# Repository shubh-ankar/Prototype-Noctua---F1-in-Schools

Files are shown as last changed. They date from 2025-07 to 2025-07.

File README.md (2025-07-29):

# 🦉 Prototype Noctua

Prototype Noctua is a miniature F1 model car we designed from scratch as Grade 12 students for STEM Racing (Previously F1 in Schools). The goal? Build something fast, aerodynamic, lightweight — and learn as much as possible while doing it.

Through design iterations, CFD analysis, and careful prototyping, we created a car that was not just regulation-compliant, but exceeded our expectations. This project helped us translate classroom theory into real engineering decisions.

---

## 🎯 Objectives

- Minimize aerodynamic drag (target: < 0.4 drag coefficient)
- Ensure directional stability via center of mass tuning
- Maximize downforce without violating regulations
- Use lightweight materials and precise manufacturing
- Apply core mechanical engineering principles (CFD, CAD, CAM)

---

## 🛠️ Tools Used

| Tool/Software | Purpose |
|---|---|
| Fusion 360 | 3D CAD modeling |
| SimScale | CFD simulations |
| CNC Milling | Chassis manufacturing |
| 3D Printing | Wings, wheels, tether guides |
| Vernier Calipers  | Precision post-manufacture checks|

---

## 📐 Methodology

### 1. **Research & Design**
- Studied F1 principles, boundary layer theory, Magnus effect
- Designed ~9 iterations of the car in Fusion 360
- Focused on smooth curvature to prevent flow separation

### 2. **Simulation & Analysis**
- Used **CFD** to study drag forces and wake patterns
- Ensured consistent test conditions with bounding boxes in simulations

### 3. **Manufacturing**
- CNC-milled chassis to precise tolerances
- SLA 3D-printed parts in resin for low mass and smooth surface
- Sanded and primed body, then painted using a tested spray process

---

## 📸 Sample Visuals

### 🔧 Final Car Render
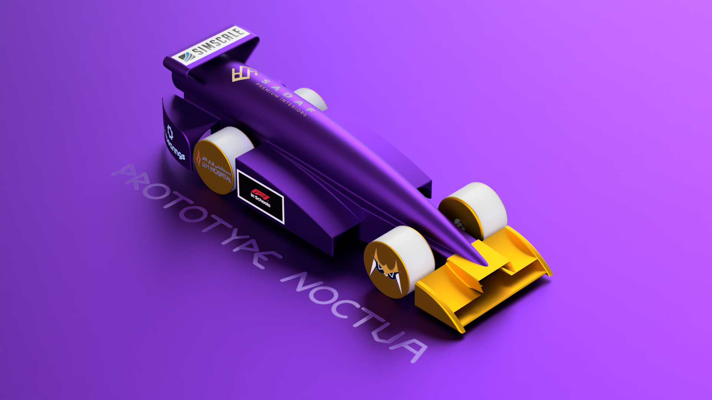
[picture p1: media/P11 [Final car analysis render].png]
Final Car

*A render of the final car body created in Fusion 360*

### 🌬️ Wake Analysis (CFD)
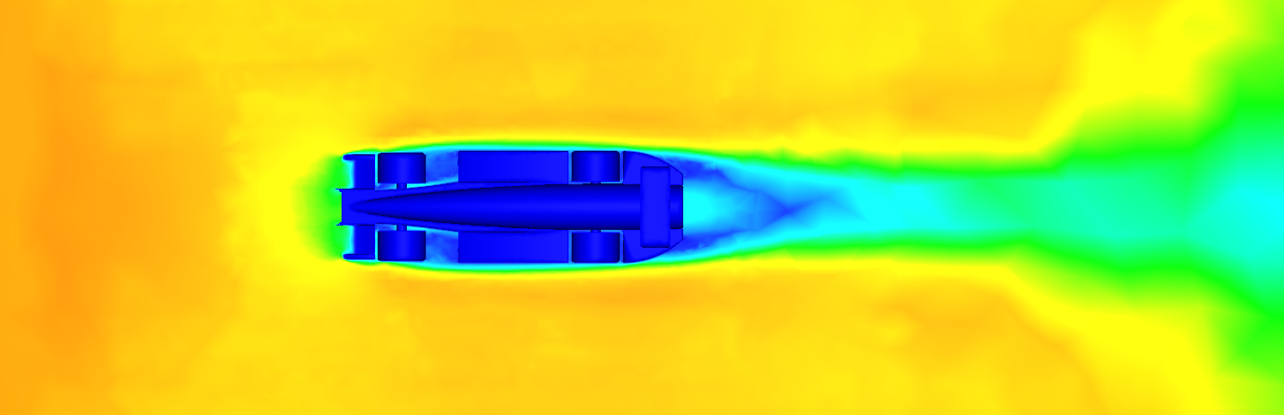
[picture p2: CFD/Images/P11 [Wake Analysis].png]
Wake CFD

*CFD wake analysis showing airflow and turbulence zones*

---

## 📊 Key Outcomes

- ✅ Final drag force: **0.28** (22% below target)
- ✅ Front wing downforce increased grip by ~15%
- ✅ Center of Mass optimized for both tip-resistance and directional control
- ✅ Weight balanced at ~50g (compliant with competition rules)
- ✅ Achieved aesthetically clean finish and structurally sound assembly

---

## 📚 What We Learned

- Iteration matters — small design tweaks made big simulation differences.
- CFD setups must be precise — boundary conditions can break results.
- Structural integrity must be balanced with aerodynamic needs.
- Manufacturing constraints (like drill bit sizes) affect CAD freedom.
- Documentation and teamwork were as important as the design.

---

## 📁 Folder Structure

```plaintext
Prototype-Noctua/
├── CAD/                        # STL files for all components
├── CFD/                       
│   └── Images/                 # CFD result images (e.g., Wake Analysis)
├── docs/                       # Project report, design plans, presentation
├── media/                      # Renders used in README
└── README.md                   # Project overview and instructions
```

---

## ✨ About the Name

**Noctua** is Latin for Owl, inspired by *Athene Noctua* — the Owl of Minerva, symbol of wisdom. Like the owl, we gained insight only after deep exploration and testing. Prototype Noctua is a reflection of that growth.

> *"Wisdom arrives only with dusk."* — G.W.F. Hegel

---

🚀 Thanks for checking out our project! Feedback is always welcome.

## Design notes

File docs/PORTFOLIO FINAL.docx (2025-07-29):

Final or sum

Car Objective:

After going through both the competition and critical regulations, we realized that the car gets us the most points. Hence, we had to keep a few clear objectives in mind so that we can acquire 100% of the allocated points. We divided the tasks in two:

1. Aerodynamics and Design:

Under this task, we had to achieve the following:

1. Drag Force of 0.4 or less | To ensure minimum point reduction from races
2. Aerodynamically efficiency | To ensure directional stability and reduce drag force
3. Innovative design that complies with regulations | Most of the allocated points can be lost in the criteria

2. Manufacturing:

Under this task, we had to achieve the following:

1. Weight | Maintain weight as close as 50g to achieve a lighter car
2. CNC milling and 3D printing | Overlook the design process to secure a millable design and decide what parts to print
3. Material selection | Select materials according to needs which are durable and easy to work with
4. Precision manufacturing | To acquire a model that closely replicates the CAD model
5. Paint | A paint that is lightweight and provides a smooth surface

These allowed us to visualize a final deliverable that would not only comply with the competition's regulations but also excel in innovation and performance maximizing the amount of points secured.

Initial Research

Through basic research of the forces a car experiences during its motion, we found that the forces experienced are: Thrust from the canister, Drag, Lift, Weight and downforce along with others.

Canister Thrust:

Canister thrust is a variable force that provides the prototype with the initial force to overcome its inertia. Hence, our goal was to maximize thrust efficiency by reducing inertia of the car and making it more streamlined. The nose cone design hugely impacts efficiency of the thrust and to achieve the highest provided thrust we need to design a nose cone that minimizes air resistance and is seamlessly integrated to the rest of the body.

Drag:

To reduce the drag, we had to ensure that the surface of the model was smooth and had smooth transitions throughout. Through applications of intricate designing techniques and aerodynamic principles, we had to make the model as streamlined as possible. To start with, we needed to create a front wing that would efficiently allow the airflow to be distributed over the rest of the body. Also, designing sidepods that flawlessly redirect airflow over and around the rear wheels such that it flows over the rear pods was essential.

Lift and downforce:

We had to minimize lift and maximize downforce so that our car is stable on the track and does not generate lift due to the initial thrust. To do so, we had to focus on the aerofoils of the front and rear wings, angle of attack of the nose cone and to implement ground effect.

Weight:

Heavier cars experience higher drag due to increased frontal area. Due to this, it’s harder to create downforce on heavier prototypes. Also, this hugely impacts inertia which can hence reduce the thrust efficiency. Hence, our aim was to create a model that would weigh as close to the 50g weight limit mandated by the regulations.

GENERAL RESEARCH

Boundary Layer Separation:

A boundary layer is a layer of fluid, which is slow-moving compared to the rest of the airflow, directly alongside a body immersed in that fluid. Boundary Layer Separation is the detachment of the boundary layer causing the formation of a wake. It occurs when the flow has reached an adverse pressure gradient where it has stopped and reversed its direction. To reduce boundary layer separation, we had to come up with a streamlined design with smooth surfaces. Filleting the edges was a major step taken in the design process as the sharp edges tended to create unwanted vortices and turbulent air flow.

Creating gradual curvature based body shapes proved to be beneficial as it maintains flow attachment and reduces adverse pressure gradients. We started to try and imply these with P7 in which we chamfered the ends of the body to replicate a gradual curve.

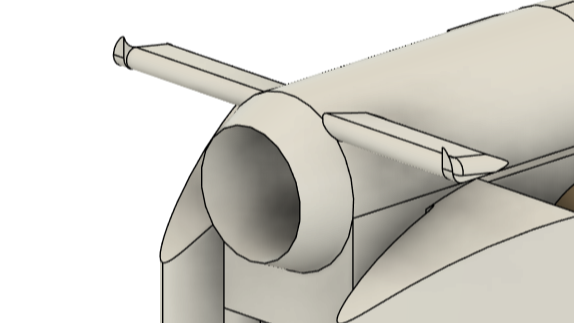
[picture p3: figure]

This evidently exhibited decrease in drag significantly but it hardly resembled a gradual curvature. We decided to look for ways to create a body that would replicate the tear drop shape and that came with the idea of the penguin shape.

Wake:

The wake is the region of turbulent airflow behind a car that is formed as it travels through air. This turbulent airflow creates a low pressure area inducing drag reducing overall efficiency.

When a body moves through air it creates a boundary layer. This layer is separated at the rear of the car creating a turbulent region with low pressure. Due to this low pressure area, a pressure difference is generated. The high pressure area at the front of the car pushes it while the low pressure area at the rear pulls it producing drag. This difference is not constant as the pressure at the rear keeps changing due to it being a turbulent area. This difference is directly proportional to pressure drag. Also, this turbulent region is more distinct with box-like rears.

Due to the wake, the car experiences a net force and can also face issues with handling.

To reduce the wake, we needed to create a streamlined design that would redirect airflow around the car.

[PIC]

Magnus Effect:

Experienced by the wheels in this case, Magnus effect is the phenomenon where, when the wheels come in contact with a fluid while moving in the opposite direction, they experience a force in a direction perpendicular to the direction of its motion. Here, wheels travel in the opposite direction of the airflow and a high pressure area is created on bottom. Due to the low relative velocity on top of the wheel, it experiences a low pressure area at the bottom of the wheel. Due to this, both a high and a low pressure area is realized, due to which a drag is experienced by the wheel. Basically, the relative speed of a wheel on top is faster than that of the vehicle and at the bottom is slower, creating rotational turbulence, inducing drag. To overcome this we needed to design a front wing that would reduce the contact of incoming airflow and the wheel.

[PIC]

Centre of Mass determination:

The center of mass of an object is the point at which the relative distribution of weight sums up to zero. For a symmetric object, the COM is in its geometric center whereas for an irregular object, the COM is at a point where the object can balance.

We considered the following to determine an approximate position for the COM:

Tipping force: (Rear COM)

The thrust provided by the CO2 canister becomes the tipping force for the car and the moment of force provided by the center of gravity of the car helps balance it out. So, our aim was to ensure that the torque provided by the tipping force should always be less than the torque by the center of mass.

T . h > W.d

T > (W . d)/h

where T is the force provided by the canister,

W is the weight of the car,

d is the perpendicular distance between W vector and the center of the front wheel,

h is the perpendicular distance between the T vector and the center of the front wheel.

Hence, we needed to ensure that the maximum force provided by the canister should be less than the right hand side (RHS).

From the equation, we see that we can maximize the RHS by either increasing the values of W or d, or by decreasing the value of h.

Since increasing the value of the weight of the car is unfavorable for other factors such as low inertia, and the value of h remains almost constant throughout the models, the only value we could afford to change was d. Hence, for a higher value of d, the center of mass was to be shifted to the back.

However, we can’t place the center of mass way towards the rear as it promotes oversteer, i.e. the car would turn more easily with a minimal force applied. Hence, we also considered directional stability of the car to balance this out. Another disadvantage of this was that it would enhance traction during the crucial moments of acceleration provided by the thrust because a high level of traction is very unfavorable as it slows down the rate of acceleration. Traction, simply put, is the frictional force which resists acceleration and helps the wheel to grip to the surface. Going by this, we can’t have extreme levels of traction so we aimed to achieve a traction in between high and low.

Directional stability: (Forward COM)

To induce understeer, we need to promote directional stability in the body which would make the chances of the car turning or changing paths less. To do so, we visualized and realized that a forward center of mass would help in maintaining the directional stability of the car along with producing lower traction in general.

To brief it up:

Forward COM | REAR COM
Promotes directional stability | Prevents the tipping moment
Promotes understeer | Promotes oversteer

From this table, we thus realized that balancing these factors is crucial and a COM right at the middle would be the most preferable for a favorable race time. Hence, after incorporating in the CO2 canisters in our model and setting the materials of 3D printed parts (i.e. front wing, rear wing, tether line guides,etc.), we achieved a center COM in the car:

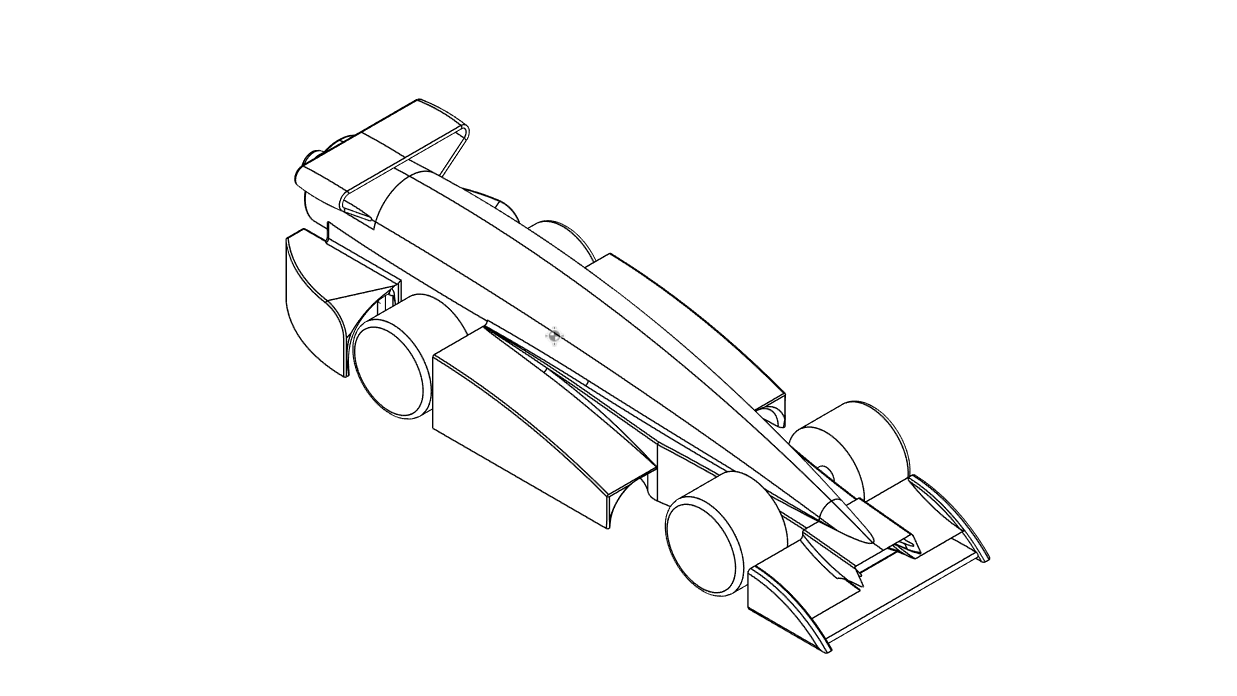
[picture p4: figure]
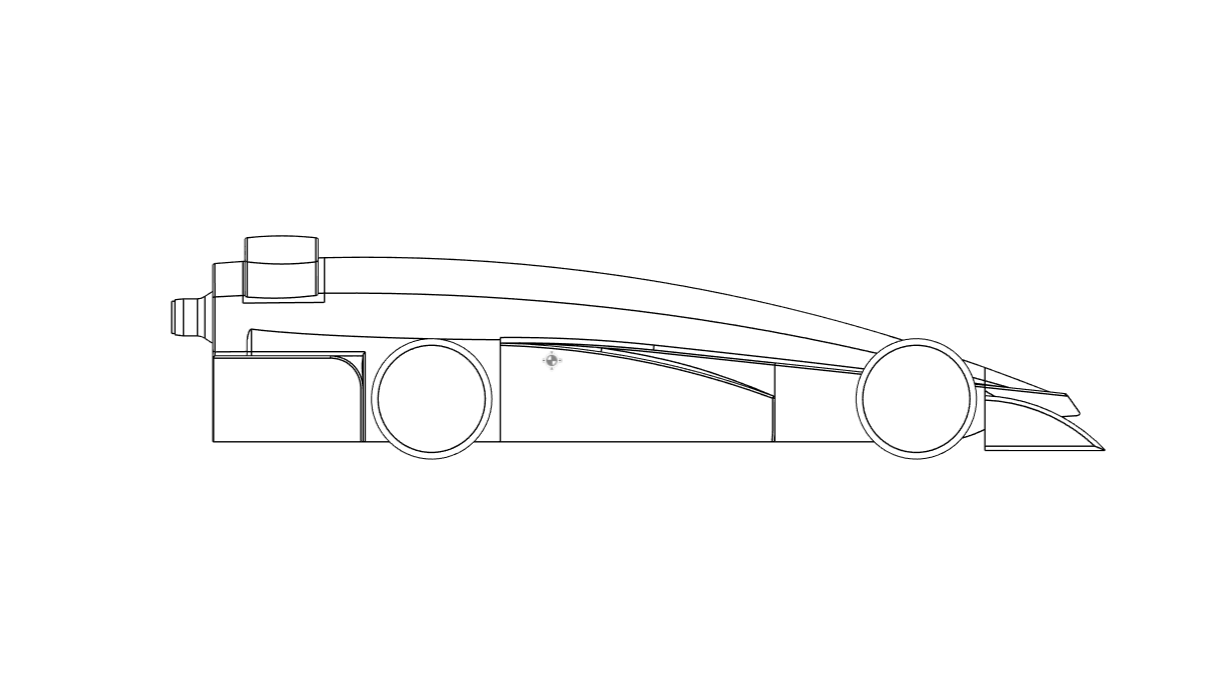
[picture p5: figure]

[USE SECOND ONE IMO]

The Centre of Mass tool displays a symbol at the observed Centre of Mass of the model. If all the materials are entered correctly, it displays the assumed Centre of Mass of the body. Indicated by

FOR CAD:

- What is CAD?

Computer Aided Design is the utilization of computers in support for designing, optimizing and analysis of any design.

The usage of CAD has proven to ease the storage, shareability and collaboration within engineers. There are 3 types of CAD softwares:

1. 2D CAD:

Aid the sketching and annotating process of a design. Mostly used for planning and layouting.

2. 3D CAD:

Aid the 3D modeling part of the designing process. 3D CAD provides an additional axis Z to facilitate 3D modeling.

It is made possible through wireframing and meshing. Wireframing is the skeletal representation of a real-world object whereas meshing is the process of dividing a complex object into smaller cells/elements.

3D CAD is of three types:

a. Parametric Modeling:

It allows users to define constraints and dimensions and edit them as soon as they have been defined. Using parametric modeling software, repetitive modifying is simplified but the existence of a history tree can stir up issues if major changes are made.

b. Explicit Modeling:

Unlike parametric modeling, explicit modeling does not rely on a history tree. The defined constraints and sketches directly become a part of the geometry created. Due to the absence of a history tree, repetitive modification is easier and expeditious. This flexibility gives the engineers the ability of rapid prototyping.

c. Assembly Modeling:

The incorporation of multiple pre-existing geometries into one.

3. Free Form CAD:

A technique that allows for the creation of more organic and graceful surfaces and solid shapes. It works on the concept of control points, splines and subdivisions. Free Forms can be combined with both parametric or explicit modeling to form complex geometries. Though it has its plus points, it is a complex technique which, if not executed well, can lead to complications like irregular transitions between two surfaces.

2D CAD | Aid the sketching and annotating process of a design. Mostly used for planning and layouting.

3D CAD

Aid the 3D modeling part of the designing process. 3D CAD provides an additional axis Z to facilitate 3D modeling.

It is made possible through wireframing and meshing. Wireframing is the skeletal representation of a real-world object whereas meshing is the process of dividing a complex object into smaller cells/elements.

3D CAD is of three types:

1. Parametric Modeling:

It allows users to define constraints and dimensions and edit them as soon as they have been defined. Using parametric modeling software, repetitive modifying is simplified but the existence of a history tree can stir up issues if major changes are made.

2. Explicit Modeling:

Unlike parametric modeling, explicit modeling does not rely on a history tree. The defined constraints and sketches directly become a part of the geometry created. Due to the absence of a history tree, repetitive modification is easier and expeditious. This flexibility gives the engineers the ability of rapid prototyping.

3. Assembly Modeling:

The incorporation of multiple pre-existing geometries into one.
Free Form CAD | A technique that allows for the creation of more organic and graceful surfaces and solid shapes. It works on the concept of control points, splines and subdivisions. Free Forms can be combined with both parametric or explicit modeling to form complex geometries. Though it has its plus points, it is a complex technique which, if not executed well, can lead to complications like irregular transitions between two surfaces.

[I ADDED THE TABLE JUST IN CASE U WANNA DO THAT SO YEE ITS THE SAME THING]

- Picking a software:

Fusion | Solid Works | Space Claim
Parametric/Explicit | Parametric | Explicit
Cloud Based | Not cloud based | Not cloud based
Simulation Tools | Simulation Tools | Ansys softwares have to be integrated
Manufacturing Integration | Manufacturing Integration | Ansys softwares have to be integrated
Free for students | Subscription | Free for students
Ease of usage | Ease of usage | Ease of usage

- Based on the above gathered information on the three of the reputed softwares, a decision had to be made to pick the ideal modeling application.
- Keeping affordability, cloud storage, user friendliness and access to training resources in mind, we chose to go with Fusion. Solid Works was immediately put aside due to its unaffordability and its high system requirements of 16 GB RAM and a quality GPU.

Space Claim was overlooked due to it being an explicit modeling software which would make it harder to edit dimensions and constraints if needed to. With the advantageous history tree, there would be no need to start geometries from scratch. Without constraints and parameters, it would’ve been hard to keep track of the design intent. Also, monitoring various parts of assemblies would be less efficient since design intent and interpart relationships are not maintained.

- Important features:
1. Sketches:

Sketches are the foundation of any geometry to be created as they define the design intent. In Fusion, shapes like circles, rectangles, ellipses, arcs, etc. are provided to ease sketching along with splines and constraints. Unconstrained sketches (indicated by: in Fusion) are useful for their flexibility and experimentality, but can affect the complex assemblies later on. Hence, it is important to create Constrained sketches (indicated by: in Fusion) once the design intent is clear to obtain a precise model.

2. Solids:

Solids are formed from sketches. Among the numerous functions Fusion provides, Extrude (indicated by: ), Loft (indicated by: ) and Sweep (indicated by: ) proved to be the most beneficial among all as evident later on.

Extrude tool adds depth to sketches. It can also be used to join (), cut () or intersect () two (or more) bodies. Loft tool creates smooth geometry between two sketch planes. Sweep tool creates a solid body along a path with a defined profile and can perform the same operations as Extrude and Loft.

3. Tools for modification of Solids:
a. Fillet:

Fillet tool () smoothens the edges of a solid body by rounding them or by adding material between two edges.

b. Chamfer:

Chamfer tool () bevels the edges of a solid body by eliminating material at the edges.

c. Combine:

Combine tool () either joins or intersects two separate bodies.

d. Align:

Align tool () aligns two separate bodies using a coordinate system.

4. Planes:

Construction Planes allow sketching in places where planar faces do not exist. These planes could also be used to use tools like Split Body (). Construction Planes can be formed at an offset from a face, at an angle or at a tangent to a surface, etc.

5. Surfacing:

Surfaces are 2D geometries that could exist on their own or as a part of a solid. Surfacing refers to the process of creation and manipulation of these 2D geometries. Basic Surfacing has been used later on during the process to increase smoothness and increase the aerodynamic capability of the models.

Functions Patch () and Stitch () proved to be the most useful in the process of perfecting the model.

FOR CFD:

- What is CFD?

Computational Fluid Dynamics is the utilization of computers to simulate the flow of fluids in different situations. It utilizes algorithms to solve the equations of fluid flow. A CFD software helps in turning a physical situation into a mathematical one which makes the simulation, visualization and analysis effortless.

The geometry which has to be analyzed is first partitioned into a mesh of small cells. The equations are then applied to each cell and the behavior of fluid within each one is analyzed which then represents the fluid's behavior over the entire geometry.

While running tests, we noticed that the boundary walls created by AutoDesk CFD significantly impacted the calculated drag force. To overcome this issue of variability, we decided to define a boundary box with identical dimensions for each and every simulation run.

CAR DEVELOPMENT

Front Wing:

Aim: Our aim was to come up with a front wing design that redirects incoming airflow around the wheels.

Our first approach was to create it at an angle with support structures at the ends. This did not give us favorable results due to poor CAD modeling.

With our 2nd prototype, we decided to design a curved front wing with an abrupt curvature. This showed promising results but we still needed to step up our modeling process.

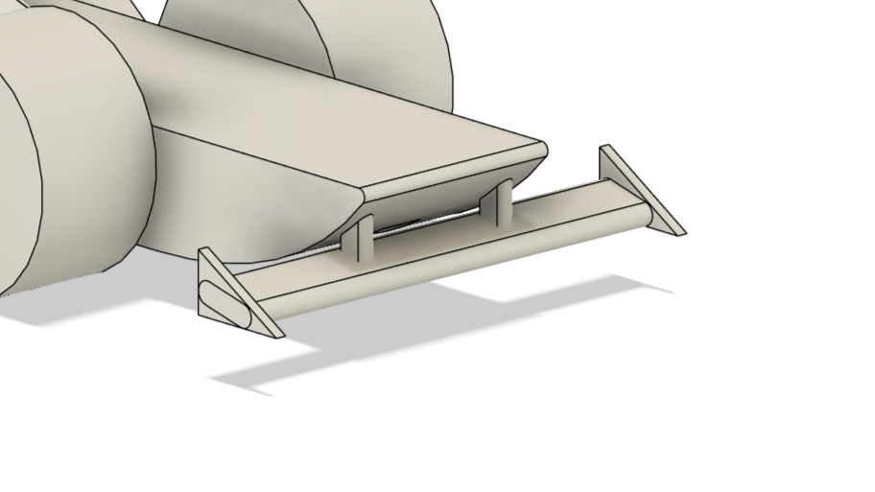
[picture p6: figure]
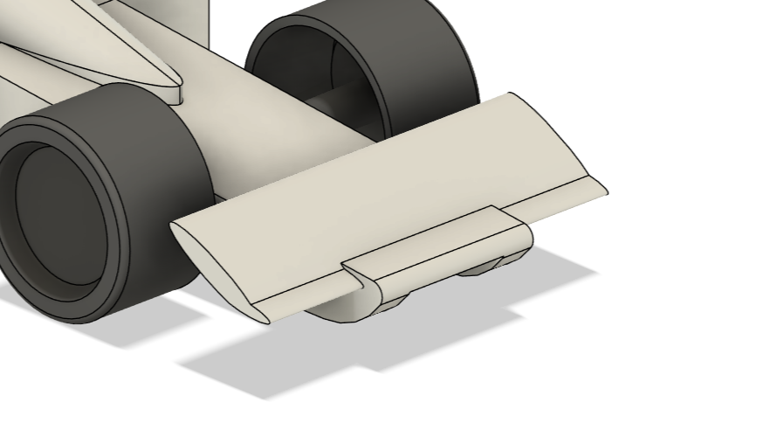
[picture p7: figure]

With the third prototype, we managed to achieve a wing with a gradual curve. This design resulted in an overall 20% decrease in drag. We felt confident with this design and decided to improve on the same.

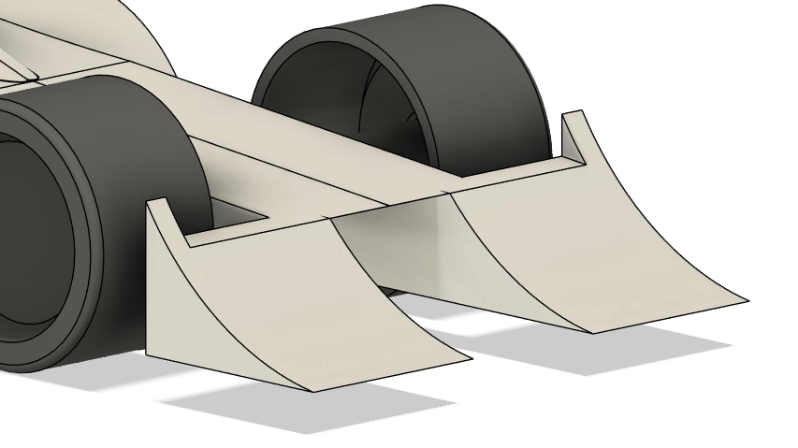
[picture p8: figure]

In the next few models, we decided to flatten half of the wing. Due to this, there was an abrupt airflow separation which directly impacted the wheels.

With the 6th prototype, there was a gradual curve on both the top and side of the wing. With this design, our intent was to redirect air flow both on top and to the sides of the wheels. We did not see any significant change due to this addition and did not pursue it.

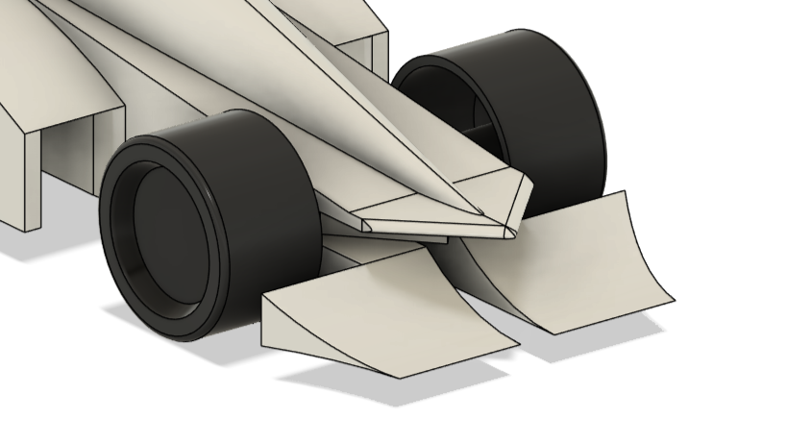
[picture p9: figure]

P7 was the pinnacle of both, a streamline and a well CAD modeled prototype. We achieved a drag force of 0.37 and was chosen as a base model to make minor changes to and experiment. After many iterations of similar designs, we decided to experiment with double elemented front wings with the curved element as basis. We tested two types of double elemented wings: straight element above (S1) and straight element below (S2).

With the S1 iterations, we saw an increase in drag force and chose to not consider it. With S2 iterations, we saw room for improvement.

S2 allowed for better boundary layer control and aerodynamic efficiency. It helped in pressure recovery which reduces drag.

Pressure recovery refers to the process of converting the kinetic pressure of a fluid to static pressure. Basically, the straight element slows down the flow of fluid, which in turn changes kinetic pressure to static. This allows for equal pressure distributions throughout the surface, decreasing drag.

Keeping the above in mind, we made minor changes to the S2. Our main focus was to come up with an aerofoil and to decide the perfect placement. We came to a conclusion that the placement of S2 will have to be in the front due to both aerodynamic efficiency and regulations which will be discussed ahead.

With the creation of Prototype Noctua, we achieved new horizons. The curved element had curvature both above and below.

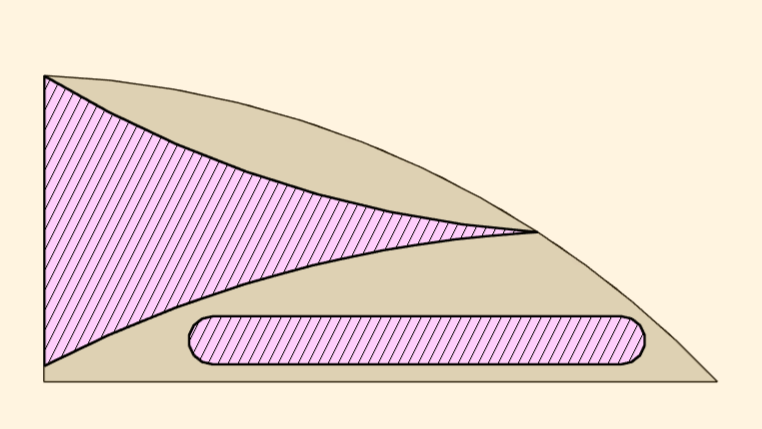
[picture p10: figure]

With the curve below, we aimed to decrease the direct impact of air on the wheels. There is a lesser curvature on the bottom as compared to the top as we did not want to create too much lift. With this iteration of the front wing we achieved an overall drag force reduction of 31.87%.

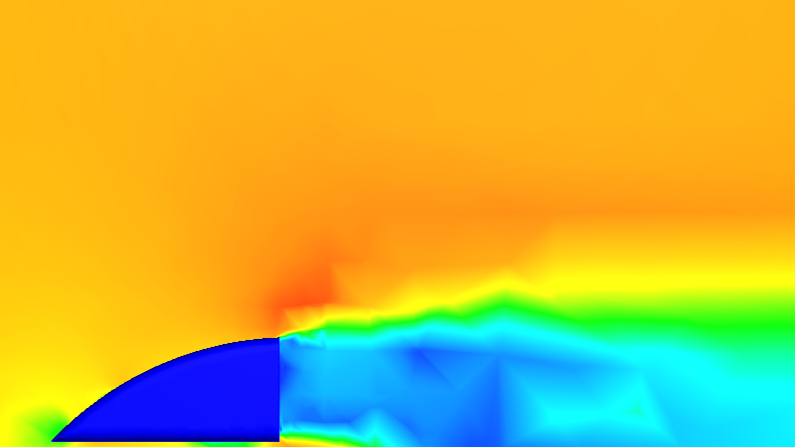
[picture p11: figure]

The above represents, in the cross-sectional form, the airflow around the final prototype of the front wing. As seen, the curved part of the front wing successfully redirects the passage of air above creating a wake behind the wing.

Rear Wing:

Aim: With the rear wing, our aim was to create a low drag, high downforce model. The model was to maintain a balance between the downforce created by it and the front wing.

With the first prototype, we dived in blind to what to expect from a rear wing other than downforce creation. With the next few models, we tried different designs to broaden our domain for the design intent. With thorough simulations, we weren’t satisfied with the results.

We randomly stumbled upon winglets, directly influenced from airplanes. With all the prototypes created before, one major issue was the creation of vortices by the ends or rear wings. This issue was solved with the implication of blended winglets. These new winglets showed immediate improvements in reduction drag.

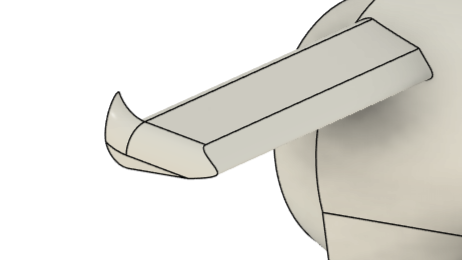
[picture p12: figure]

But with the creation of winglets, the issue of creation of vortices was not completely resolved. To completely eliminate vortices we decided to create a wing that resembles a F1 car. The ‘curved wing’ concept used in F1 reduces drag significantly. But the regulations of the competition differ from the ones set by F1 In Schools and so we had to modify them so that they follow them. We ended up with an inverted triangle as our rear wing.

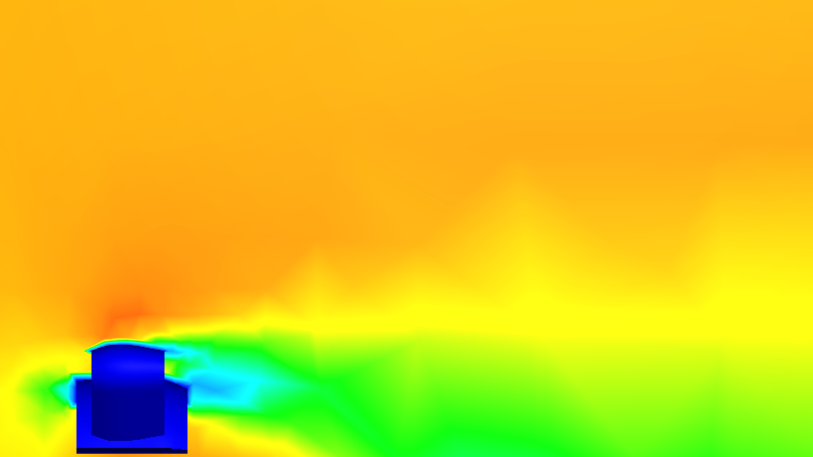
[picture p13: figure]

The first of the two chosen prototypes, though effectively helped in managing the turbulent air flow that would be created in the wake of the car hence reducing drag, had us concerned with its structural integrity as it was modeled to be wafer-thin to maintain the low drag aim. Hence, we had to discard this prototype. But this set a foundation for the design intent of the final rear wing.

This final prototype was modeled to have a thicker leading and trailing edge. It was raised higher to maintain the required 3 mm distance mandated by the regulations. The support structures were angled lower to cover a larger area of airflow. This helped us improve the structural integrity significantly while maintaining the design intent.

We used the NACA 0012 for these iterations of the rear wing. It provided close to no lift at the 0° angle of attack. Due to its symmetry, it could be easily manufactured with great structural integrity and predictable aerodynamic characteristics.

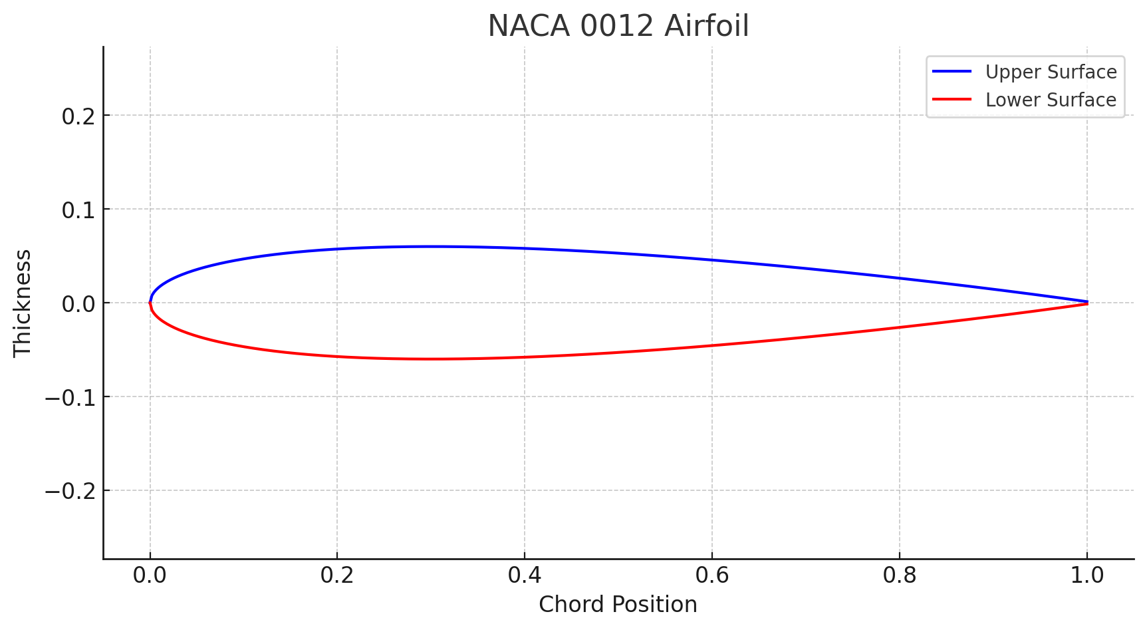
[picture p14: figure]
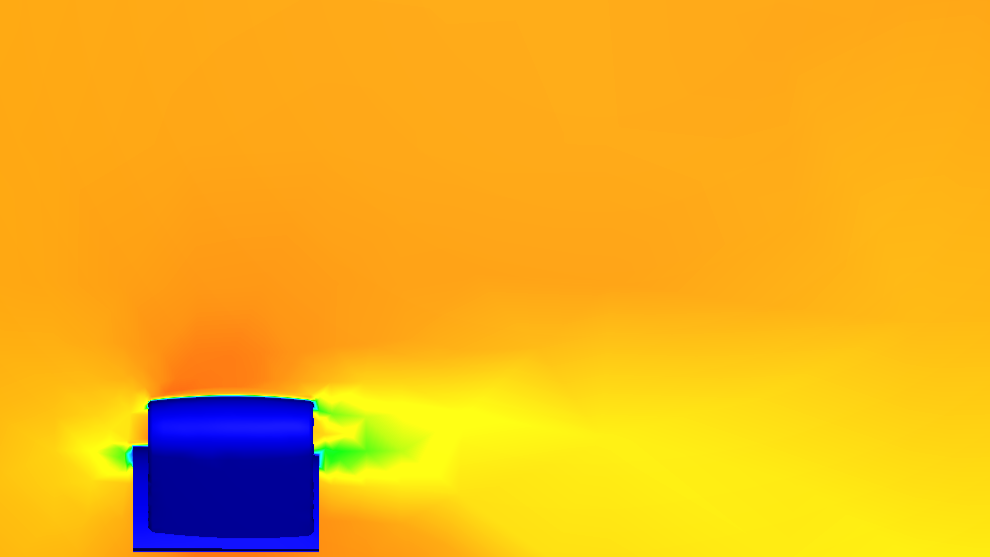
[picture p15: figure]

While being a more streamlined design by almost 30%, it also proved to be more efficient in maintaining the energy of the airflow it faced. Hence, this design was chosen as the final rear wing.

Sidepods And Rearpods:

During the initial phase of designing, we focused on perfecting the front and rear wings. Even still, our design intent gets its foundation from the first few models.

Aim: Our aim was to create sidepods such that they redirect airflow over the rear wheel and to ensure smooth flow along the sides.

Our thought process led us to creating hollow sidepods, which would prove to be helpful in minimizing wake turbulence and increasing downforce and stability of the prototype on the track. Our initial design was an opening right into the rear wing, which remarkably reduced drag but could have been improved.

Then it was decided to create an opening towards the sides of the car. Implementing this on P7, we achieved our first exceptionally streamlined model.

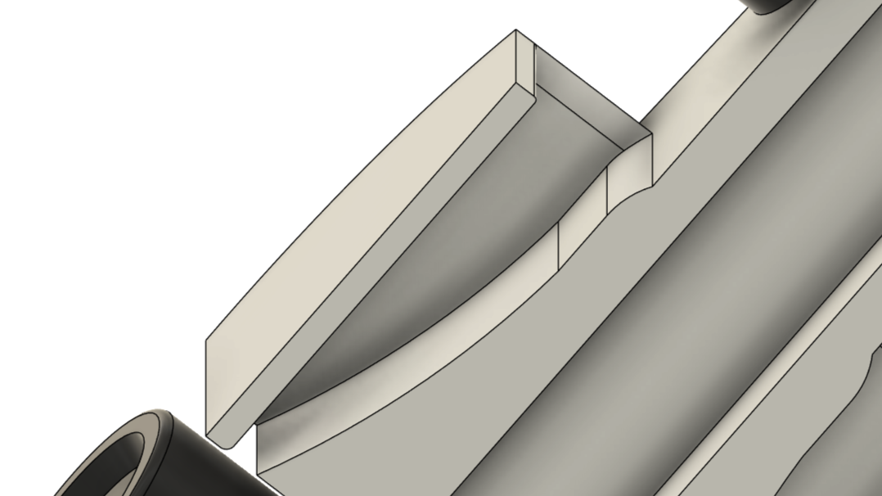
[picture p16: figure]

With rigorous analysis through CFD, we realized that this design, with its benefits also had its drawbacks. The opening for the airflow to pass was miniscule. This would trap a significant amount of airflow and redirect it under the car diminishing ground effect. Also, due to the use of the 6.35 mm diameter drill bit, the manufacturing of the tiny opening would’ve been impossible. This was later rectified in P7.

This and the passion for a lower drag prototype led us to hollowing them in such a way that the passage opens to the tether line guide slot.

Along with this, we lowered the sidepods significantly. Through analysis we noticed that the airflow right above the front wheels would slip into the low pressure area created behind the wheel creating turbulent airflow into the sidepods. Hence, it allowed the sidepods to work more efficiently than before and regulate airflow as intended to. Lowering of sidepods helped in moving the center of mass down as well.

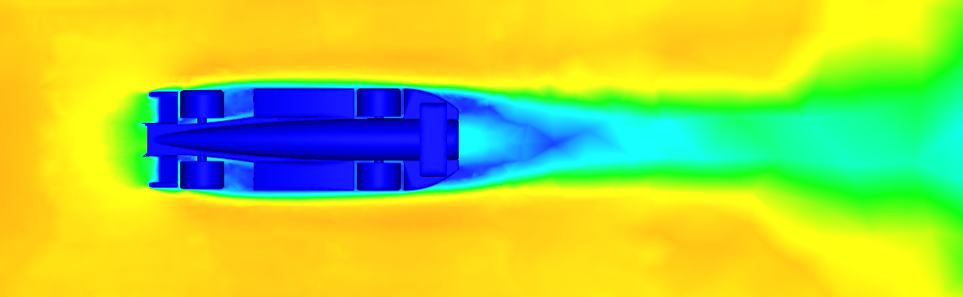
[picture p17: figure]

From the CFD analysis of the prototype, it is seen that the low pressure area behind the wheel as well as airflow along the sides is maintained throughout.

Aim: Our thought process, when we were coming up with designs for the rear pods, was to use them to redirect the passage of air to the rear low pressure area of the car.

We ran through multiple iterations and ended up, once again, with a V. This design allowed for the airflow from the tether line slot to spread up and for the flow from the sides to be averted towards the rear.

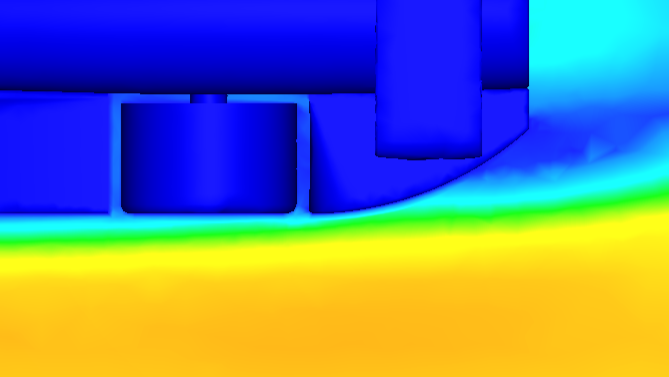
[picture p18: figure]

Due to the slope of the rear pod, the airflow is not fully pivoted to the rear but there is a late separation of air flow which was ideal.

With P6 and P8, we tried to hollow out the rear pods as some of the airflow would get trapped between it and the rear wheel. But due to poor CAD modeling, this strategy did not prove fruitful. This plan was originally thought to be discarded but made a return with the final few versions of Noctua. With the improved modeling efforts, this hollowing, though not a cake walk, proved yielding.

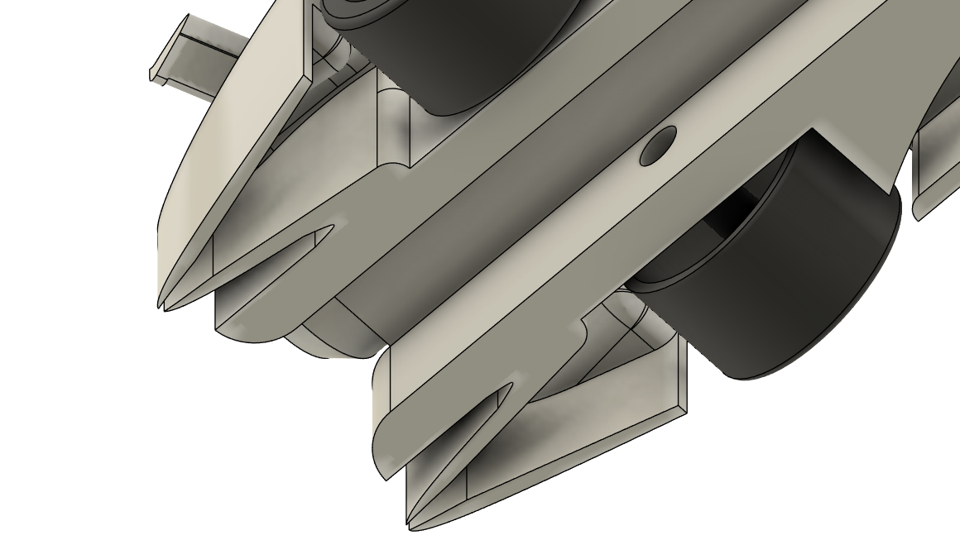
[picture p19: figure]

All these changes to the side and rear pods helped in streamlining the car the most. It proves how important these two components are for directional stability, aerodynamic efficiency, generation of downforce, etc.

Nose Cone:

Aim: Our aim with the nose cone was to create a flat surface that would not let the airflow flip onto the wheels.

Initial designs led us to realizing that the airflow would roll over into the wheels and hence we decided to go with a more refined nose cone. Taking inspiration from a sword, the nose cone created for models P6-P9 served its purpose right, slashing through the wall of incoming air and significantly reducing the slip-off factor. The junction between the nose cone and the main body was sharp and had to be filleted with a G1 continuity factor to smoothen the transition.

We later switched the design to a wedge as the ‘edge of a sword’ concept, despite its functionality, resulted in a sudden impact from the incoming air, leading to occasional turbulence.

Car Body:

The most streamlined shape in the world is the teardrop with a drag coefficient of 0.05. But during the design process of the body, we realized that implication of such a shape would not be possible. We decided it would be best to elongate the body so that there is a gradual flow of air along it. Chamfering further reduced the drag but was not satisfactory.

To overcome this we needed to brainstorm a solution that would result in a penguin-like shaped body.

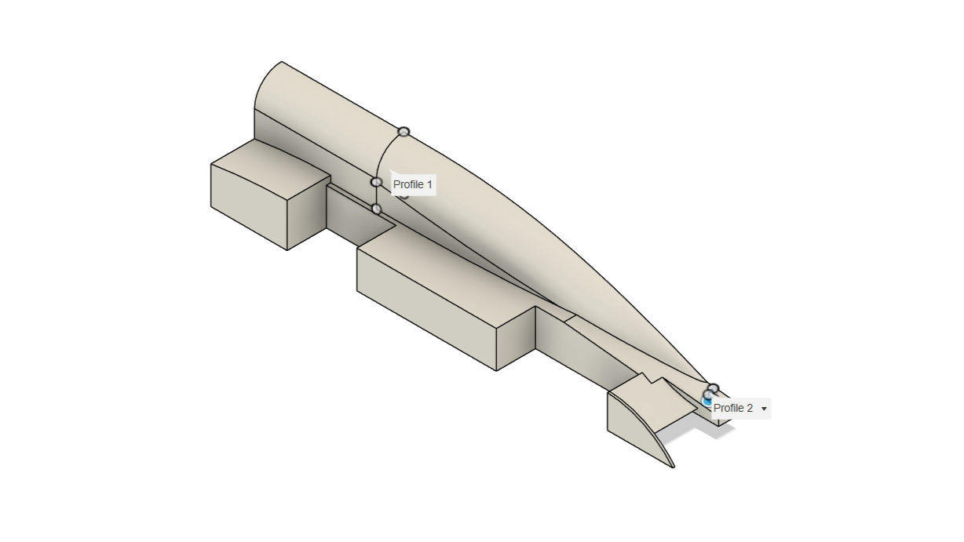
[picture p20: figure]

Initially, we would extrude (mentioned above) a chamber for the CO2 first and then create a sketch further away and loft (mentioned above) the two profiles (the face of the chamber and the created sketch), but this resulted in a gradual curve only at the front of the body. The air flow would separate over the chamber hence, widening the wake and inducing drag.

Our line of thinking then shifted to using forms to create a curvature around the chamber. This resulted in an increased drag due to the lack of continuity from the loft to the created form.

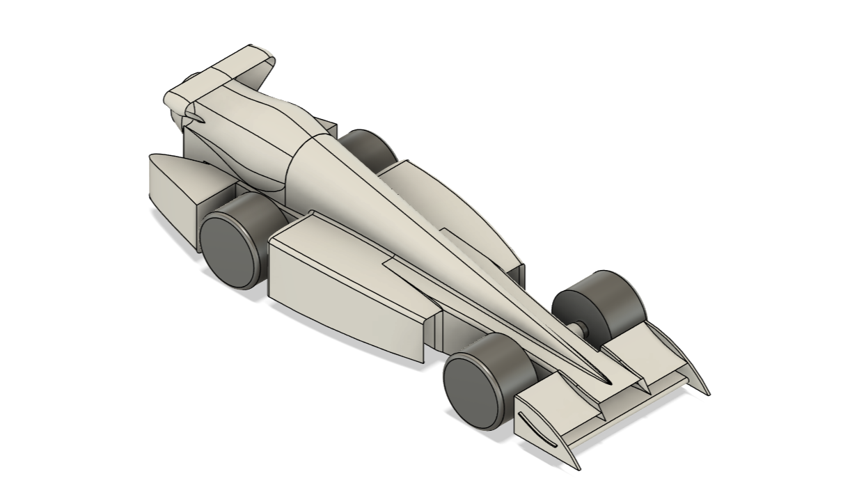
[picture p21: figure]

We decided to create two sketches: one at the rear of the car and one on the face of the chamber, both of which consisted of a semicircle. The semicircle at the face was given a longer base by 2mm. On lofting, we were able to produce a body with an exceptional curve.

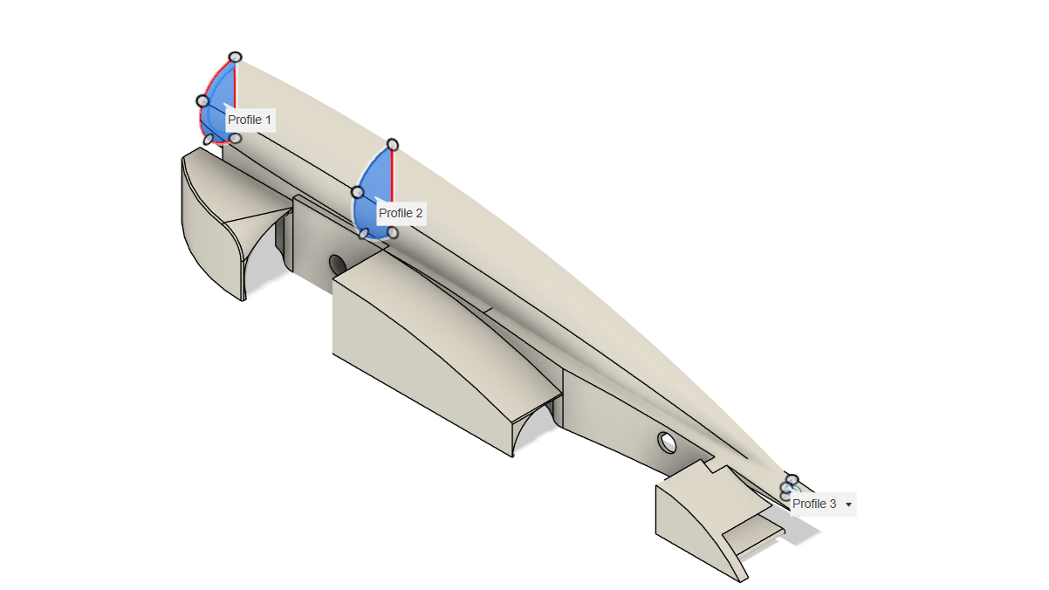
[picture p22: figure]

- All the sharp edges along the side/rearpods, nose cone and the junction between the nose cone and the body had been filleted to create smooth surfaces that reduce turbulence and flow separation resulting in a smoother model that is easier to manufacture as well. One of the biggest advantages of these fillets is the improved stress distribution offered, increasing structural integrity.
- To aid in acquiring smooth edges with fillets, we used surfacing. Surfacing allowed for creation of smoother transitions that were precise and continuity. It permitted not only an aesthetic and streamlined design but also simplified the model to encourage easier milling.

[ADD IN BOX AT THE END?]

Other Design Concepts

Diffusers:

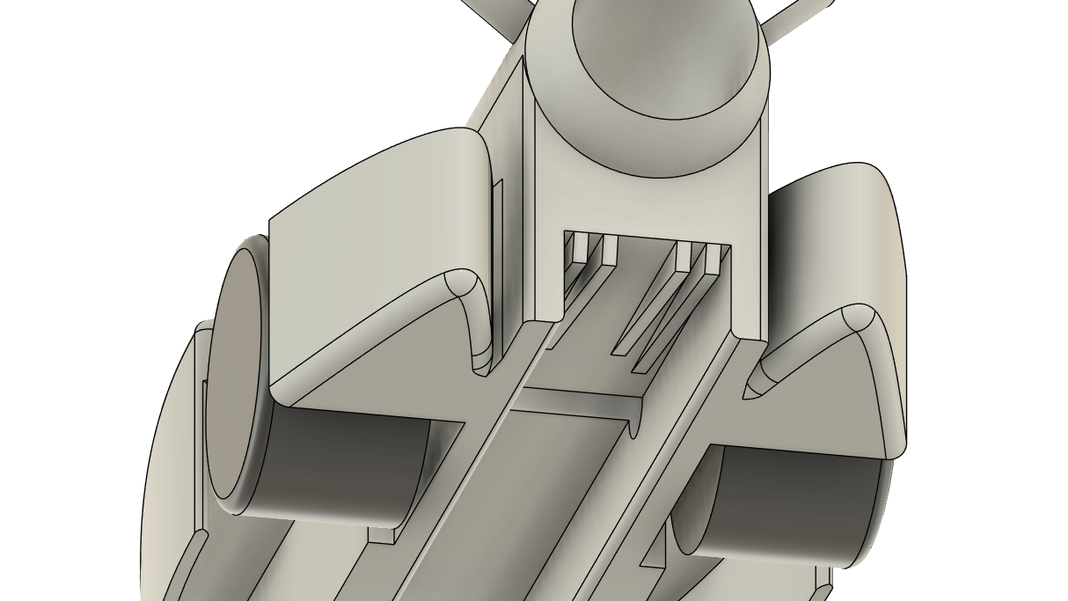
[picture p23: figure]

Diffusers are parts at the rear which increase cross sectional area gradually to slow down passage of air to redirect it to the low pressure area in the rear of the car. These helped in reducing the drag significantly at the time, but upon revision of the regulations, we realized that the use of diffusers would result in a broken critical regulation and hence, we dropped the idea.

Vortex Generators:

Inspired by F1 cars, we tried to create vortices by adding vortex generators to the front wings to reduce boundary wall separation along the sides of the models but again, we violated critical regulations and had to get rid of them.

Final Car Analysis

[Render]

Prototype Noctua was found to have a drag force of 0.28. After meticulous research and testing, we realized a car that was aerodynamically efficient, structurally sound and aesthetically pleasing.

Our final model, Prototype Noctua, surpassed our initial expectations, compelling us to delve deeply into CAD modeling and achieve new heights in aerodynamics application.

Analysis Tools:

Curvature Comb:

This tool allows for the analysis of the curvature of a surface. It displays perpendicular lines along the surface (making it look comb-like) whose lengths are directly proportional to the curvature at that point. If the length of the line is longer, the curvature is high and if the length is shorter, the curvature is lower.

Continuity G:

Known as Geometric Continuity and is the continuity between two geometries. It decides the smoothness of a surface.

a. G0: G0 or Positional continuity occurs when two surfaces have a common endpoint. It requires the geometries to meet each other.
b. G1: G1 or Tangential continuity occurs when the two surfaces have the same tangential direction.
c. G2: G2 or Curvature continuity occurs when the two surfaces have the same curvature, ensuring a smooth transition.

Zebra Analysis:

Zebra Analysis utilizes stripes identical to a Zebra’s stripes (hence the name) to analyze the continuity and smoothness of a surface. Parallel lines are produced over a surface and the deviation of the ‘stripes’ is visualized conveying the irregularities of the curvature. To make certain there are no irregularities, ensuring that the distance between consecutive lines is consistent.

With the above analysis, we can interpret that the model has somewhat consistency in the distance between each line. The view of Zebra Analysis changes when the model is moved and hence, we get a different representation at every view point.

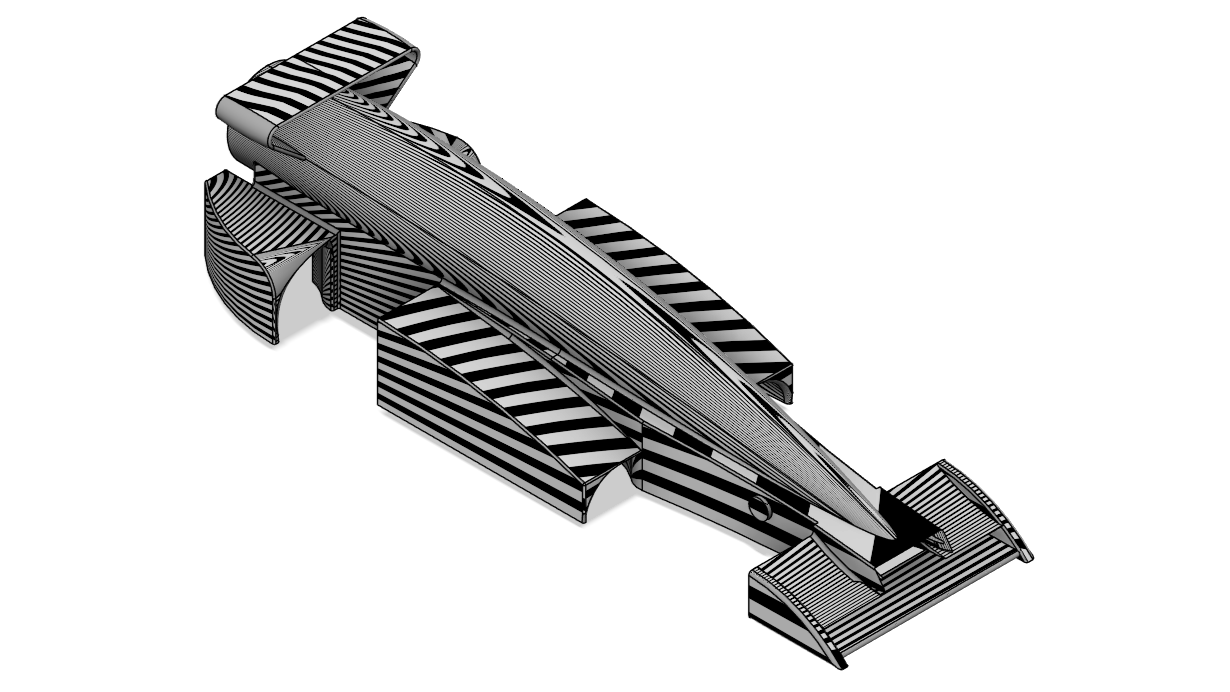
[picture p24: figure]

Accessibility Analysis:

This tool evaluates whether a given geometry can be accurately manufactured using CNC machines. Accessibility, in this context refers to whether a model can be reached by the end mills and whether there is a chance of potential collision of the tool with the material.

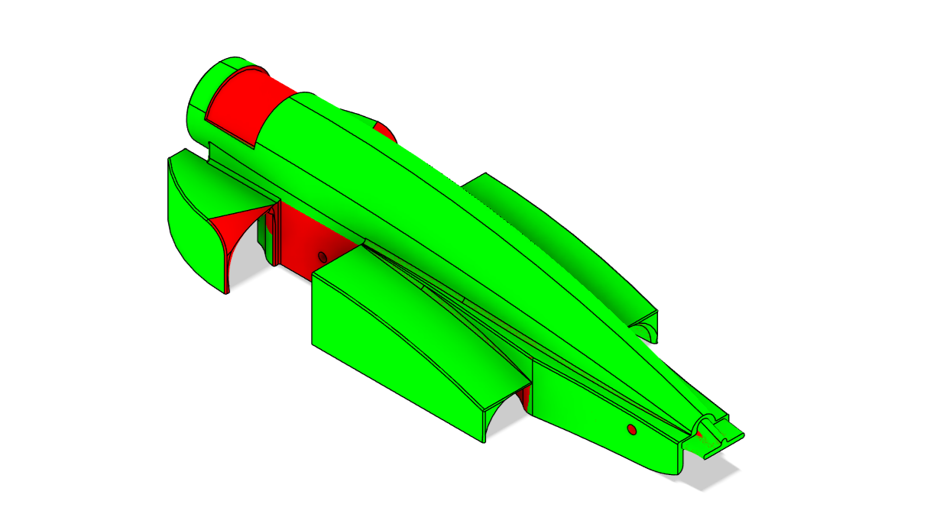
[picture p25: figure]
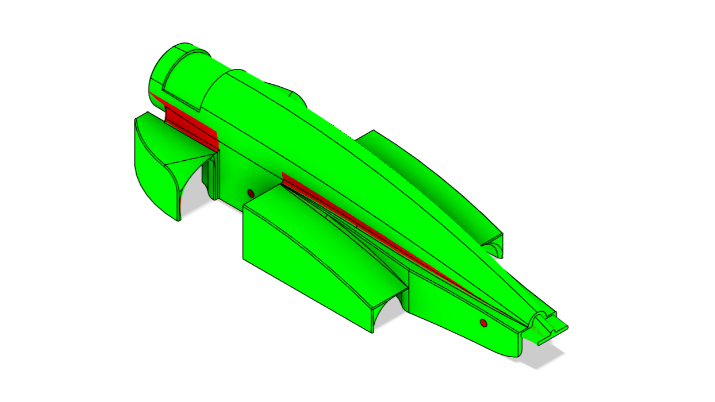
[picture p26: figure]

From the above three representations of accessibility from each plane, it can be inferred that the model will not have issues with the CNC process. The axle holes are not considered as the end mill does not have the required diameter to CNC the feature.

[Couldn’t think of a place to enter here but if u feel its somewhere better within final car analysis then go ahead]

‘Noctua’ is derived from ‘Athene Noctua’ or Owl of Minerva. The Owl of Minerva symbolizes the arrival of wisdom and knowledge after the events have unfolded. Georg Hegel, a German philosopher, popularized the phrase “The Owl of Minerva spreads its wings only with the falling of dusk” representing just that.

This is exactly what we experienced during the constant designing of models. We were not equipped with the knowledge to create such a remarkable model, it only came to us after thorough trial and error and extensive research.

Our initial goal of achieving a drag force of 0.4 or lower became obsolete after we realized what the Noctua was truly capable of. Through practice, we managed to achieve a streamlined body that could withstand the forces presented to it during the races.

The front wing achieved its initial goal of creating downforce while also keeping the airflow away from wheels. It was also able to energize airflow hence decreasing boundary layer separation and increasing downforce and thus, improving stability and grip.

The rear wing realized its task of being a low drag element that redirects airflow towards the wake of the car while providing downforce and hence stability.

The sidepods beautifully carry the oncoming airflow from the wheels and elegantly redistribute it over the rest of the car body adding to the directional stability and grip.

The rear pods allow the latency in airflow separation hence, averting the airflow towards the rear of the car. They also carry the airflow over the rear wheels and help reduce turbulence which adds to the overall aerodynamic efficiency of Prototype Noctua.

Hence, Prototype Noctua helped us in realizing our own potentials and to what extent our boundaries could’ve been pushed to. With Noctua, we achieved new horizons.

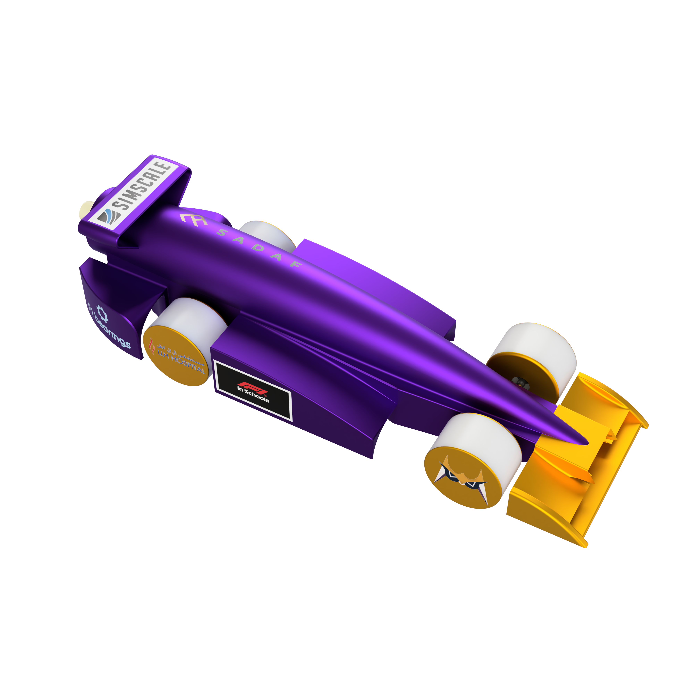
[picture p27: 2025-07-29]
media/P11 [render for poster 1].png

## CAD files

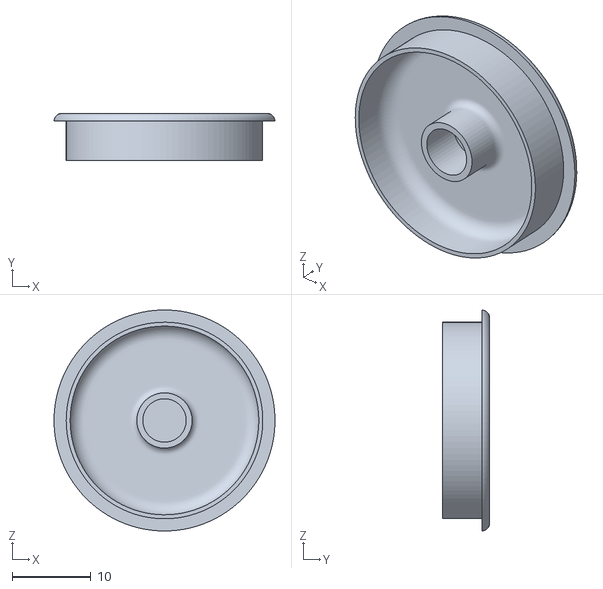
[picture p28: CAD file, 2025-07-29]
CAD/FINAL [Extra stl Files]/wheeeee v3_hubcap_.stl
28.0 x 6.00 x 28.0

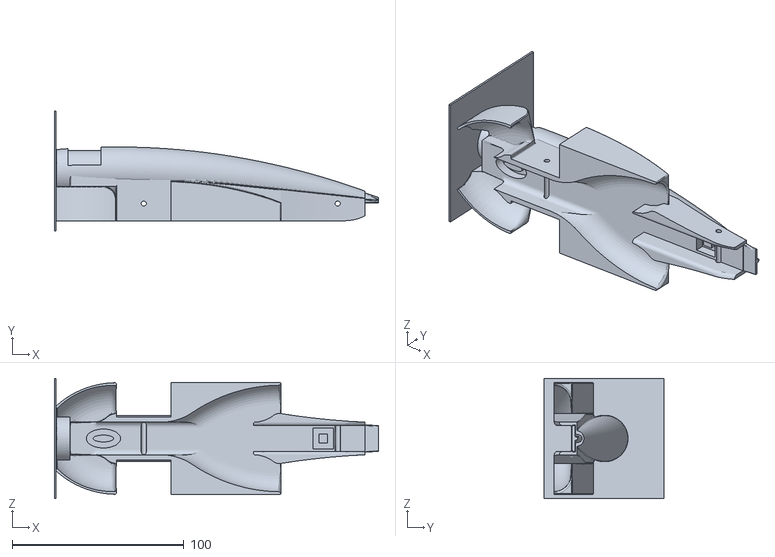
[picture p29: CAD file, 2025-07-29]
CAD/FINAL/Team Minerva Car Body Revision 1.stl
188.8 x 70.0 x 70.0

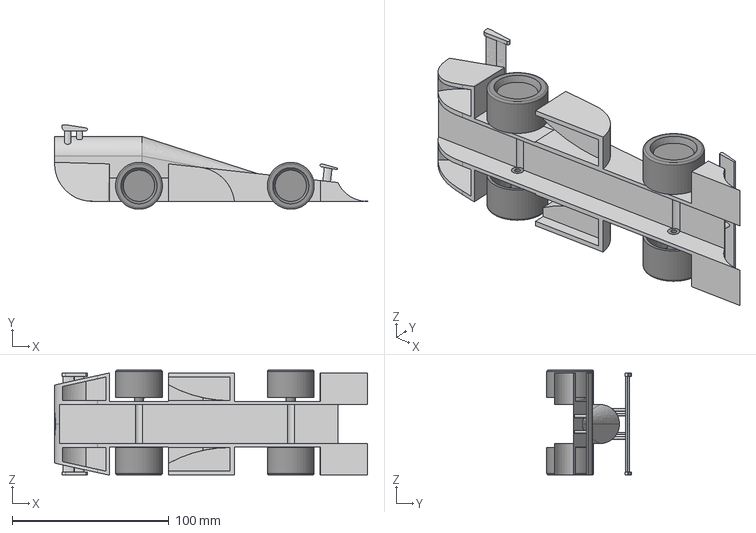
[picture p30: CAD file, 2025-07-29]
CAD/P4.step
200.0 x 54.0 x 67.0 mm
f1_wheel v1 x 4

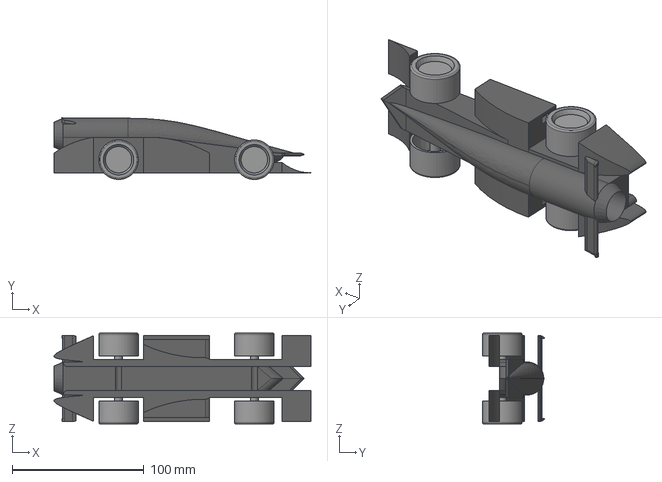
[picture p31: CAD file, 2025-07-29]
CAD/P7 Iterations/P7.step
195.0 x 47.0 x 69.0 mm
f1_wheel v1 x 4

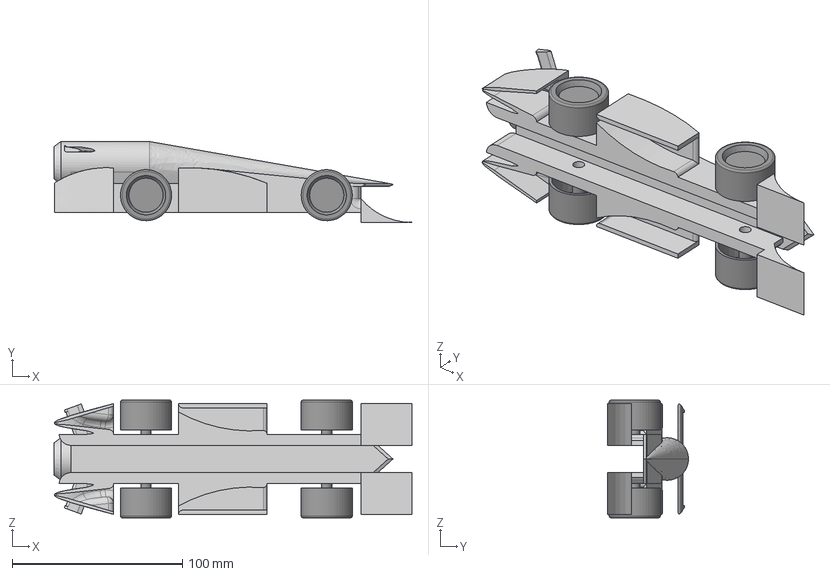
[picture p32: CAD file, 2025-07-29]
CAD/P8 Iterations/P8.step
210.0 x 47.5 x 69.0 mm
f1_wheel v1 x 4

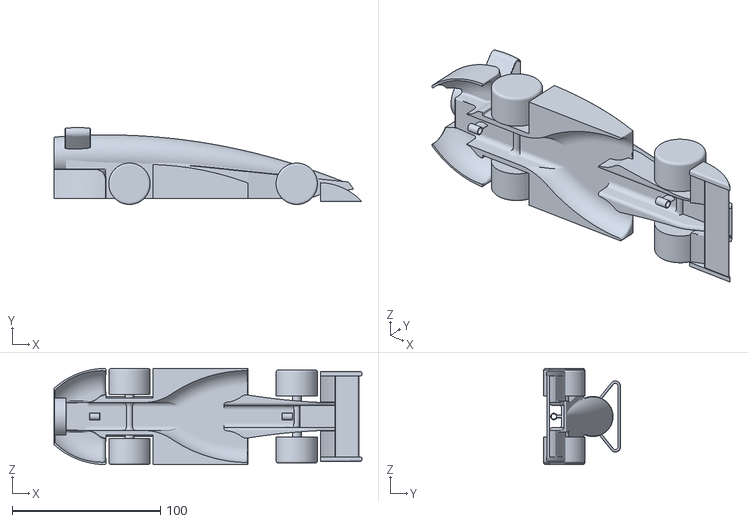
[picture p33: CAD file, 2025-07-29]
CAD/FINAL [Extra stl Files]/P11_.stl
208.0 x 52.0 x 65.0

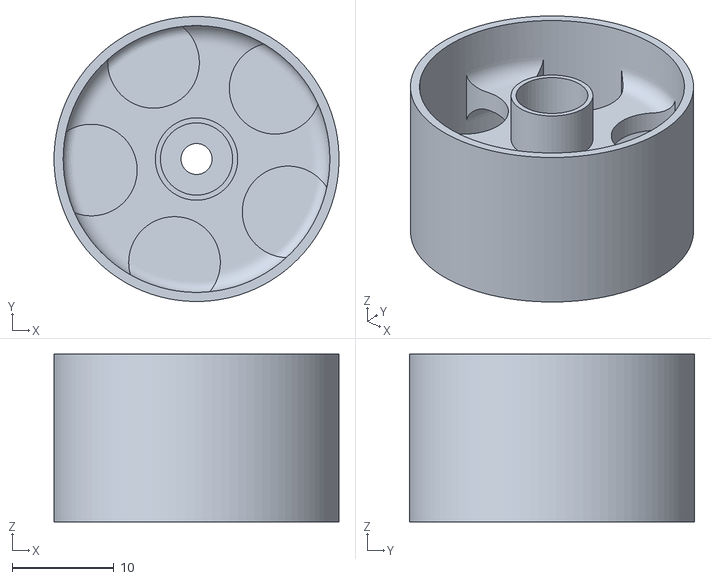
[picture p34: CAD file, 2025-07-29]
CAD/FINAL/P11_wheel [Final].stl
28.0 x 28.0 x 16.5

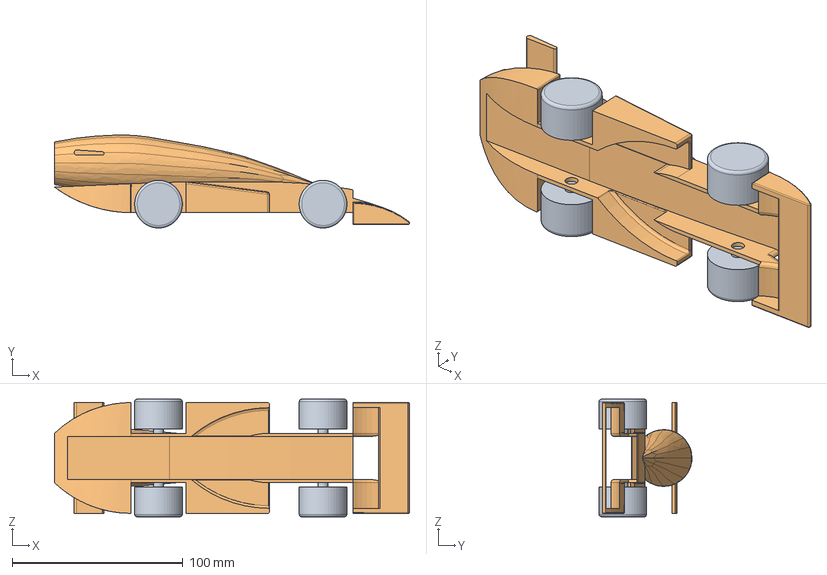
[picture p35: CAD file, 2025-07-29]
CAD/P12.step
208.2 x 54.5 x 69.0 mm
F1 Wheel [28mm] x 4

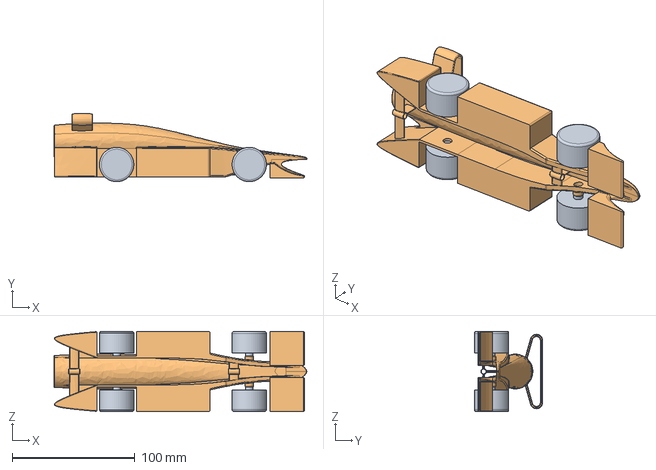
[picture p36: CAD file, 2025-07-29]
CAD/P13 Iterations/P13 [v2].step
206.0 x 55.7 x 65.3 mm
F1 Wheel [28mm] x 4

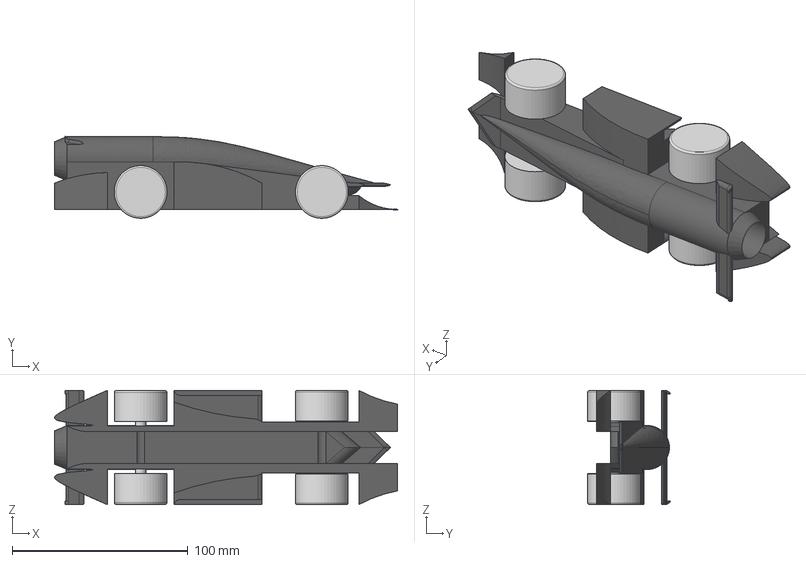
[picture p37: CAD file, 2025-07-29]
CAD/P7 Iterations/P7 [re-3].step
195.0 x 47.0 x 65.0 mm
F1 Wheel [P7-2] x 4

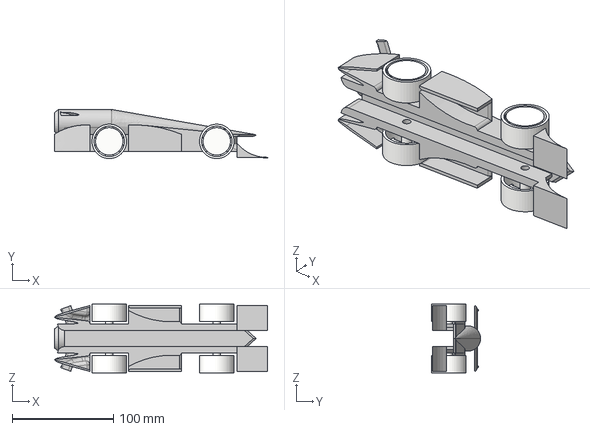
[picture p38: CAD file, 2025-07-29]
CAD/P8 Iterations/P8 [wheels].step
210.0 x 48.5 x 68.0 mm
Wheel [P1] x 4

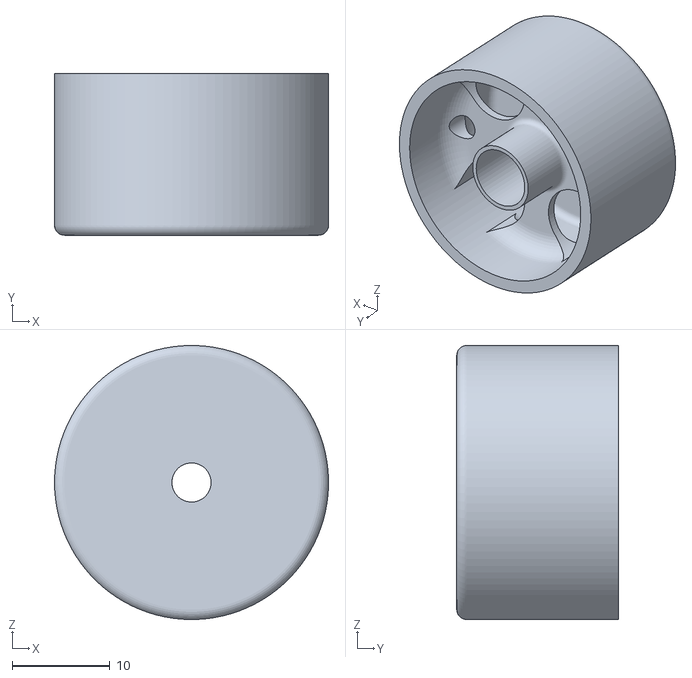
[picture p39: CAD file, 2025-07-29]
CAD/FINAL [Extra stl Files]/wheel [for print]_.stl
28.0 x 16.5 x 28.0

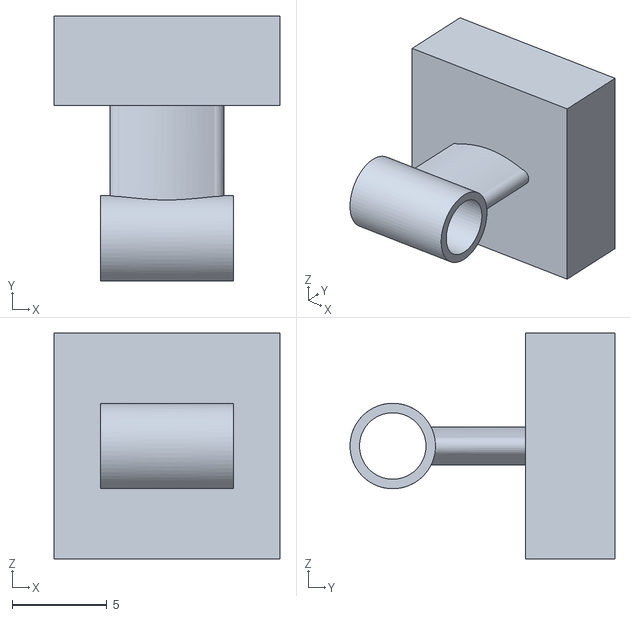
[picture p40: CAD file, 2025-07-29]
CAD/FINAL/Team Minerva Tether Line Guide [Front] Revision 1.stl
11.9 x 13.9 x 11.9

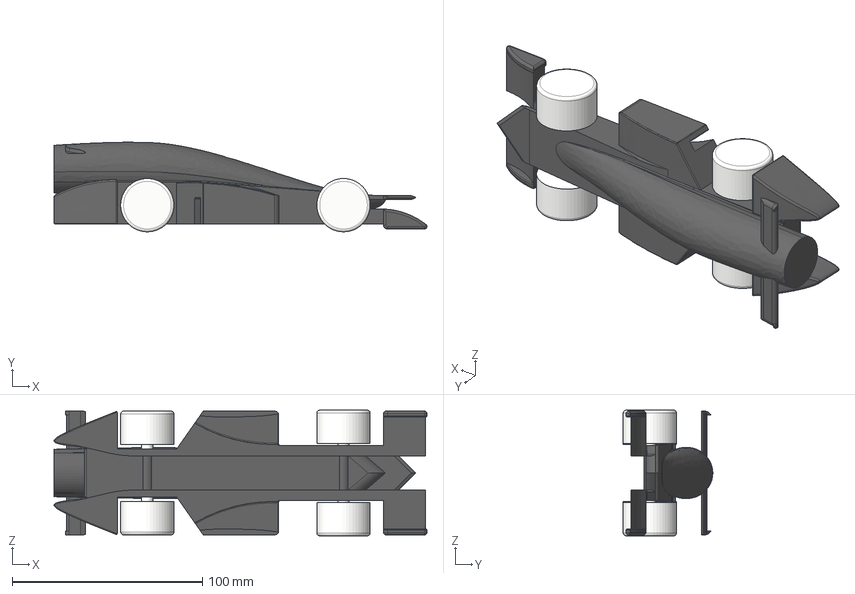
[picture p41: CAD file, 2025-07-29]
CAD/P7 Iterations/P7 [re-5].step
195.8 x 47.1 x 66.0 mm
F1 Wheel [28mm] x 4

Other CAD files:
CAD/P11 Iterations/P11 [front wing-straight].step
CAD/P8 Iterations/P8 [re-3].step
CAD/P9.step
CAD/FINAL [Extra stl Files]/P11_Tether Line Guide - [Rear]_.stl
CAD/FINAL [Extra stl Files]/P11_Rear WIng [Final]_.stl
CAD/FINAL/P11_Hubcap [Final}.stl
CAD/FINAL/Team Minerva Front Wing Revision 1.stl
CAD/FINAL/Team Minerva Tether Line Guide [Rear] Revision 1.stl
CAD/P1.step
CAD/P10.step
CAD/P11 Iterations/P11 [FINAL].step
CAD/P11 Iterations/P11 [front wing-less curved]_.step
CAD/P11 Iterations/P11 [v10].step
CAD/P11 Iterations/P11 [v11].step
CAD/P11 Iterations/P11 [v12-t2].step
CAD/P11 Iterations/P11 [v12].step
CAD/P11 Iterations/P11 [v1].step
CAD/P11 Iterations/P11 [v2].step
CAD/P11 Iterations/P11 [v3].step
CAD/P11 Iterations/P11 [v4].step
CAD/P11 Iterations/P11 [v5].step
CAD/P11 Iterations/P11 [v6].step
CAD/P11 Iterations/P11 [v7].step
CAD/P11 Iterations/P11 [v8].step
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

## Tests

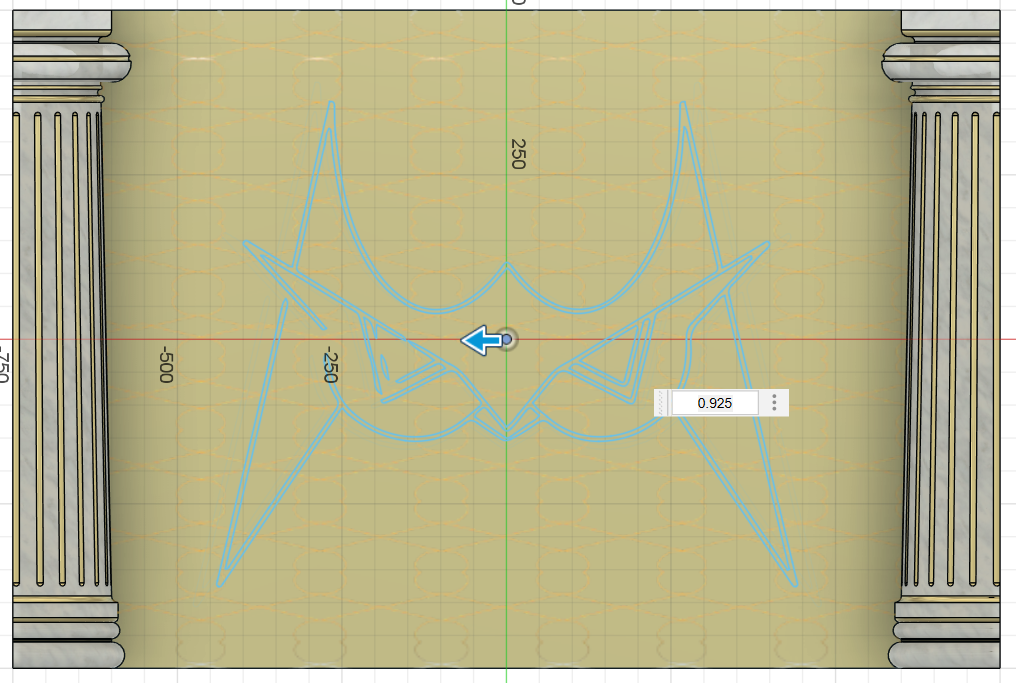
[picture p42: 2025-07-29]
media/misc. [Tests, screenshots, etc.]/Screenshot 2024-06-16 160849.png

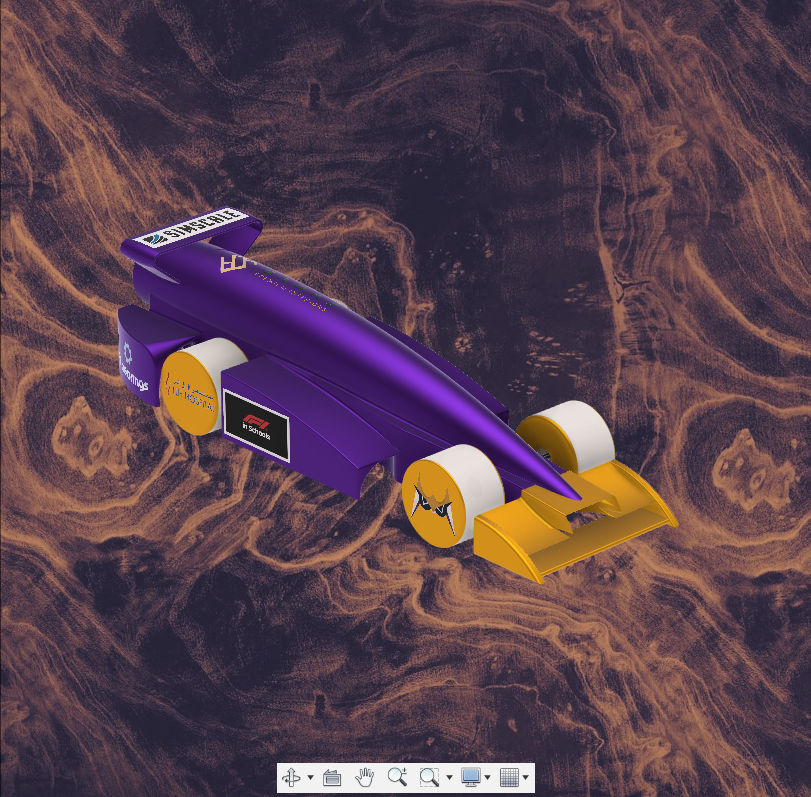
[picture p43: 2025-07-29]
media/misc. [Tests, screenshots, etc.]/Screenshot 2024-06-15 132048.png

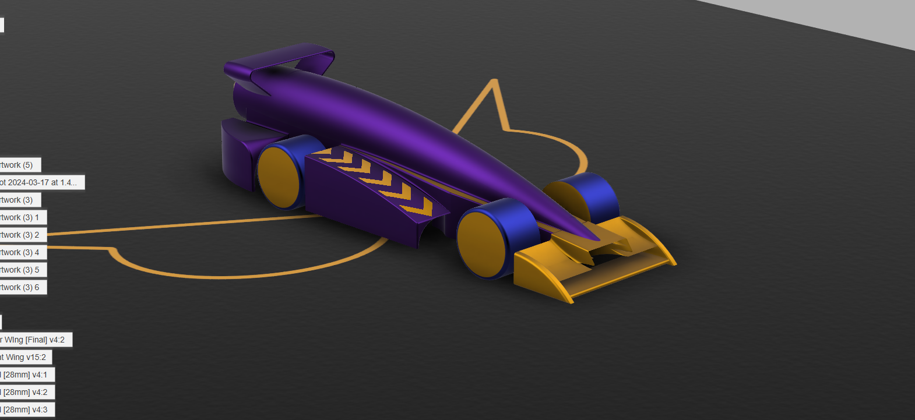
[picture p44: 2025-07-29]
media/misc. [Tests, screenshots, etc.]/Screenshot 2024-06-09 211904.png

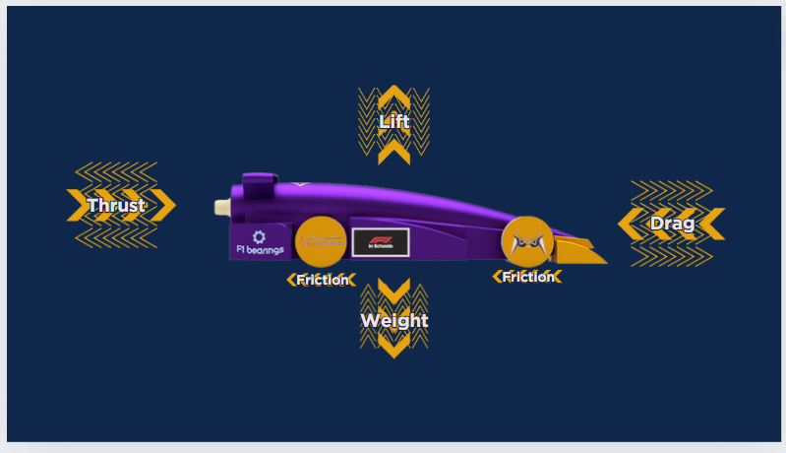
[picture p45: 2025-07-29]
media/misc. [Tests, screenshots, etc.]/Screenshot 2024-06-15 205451.png

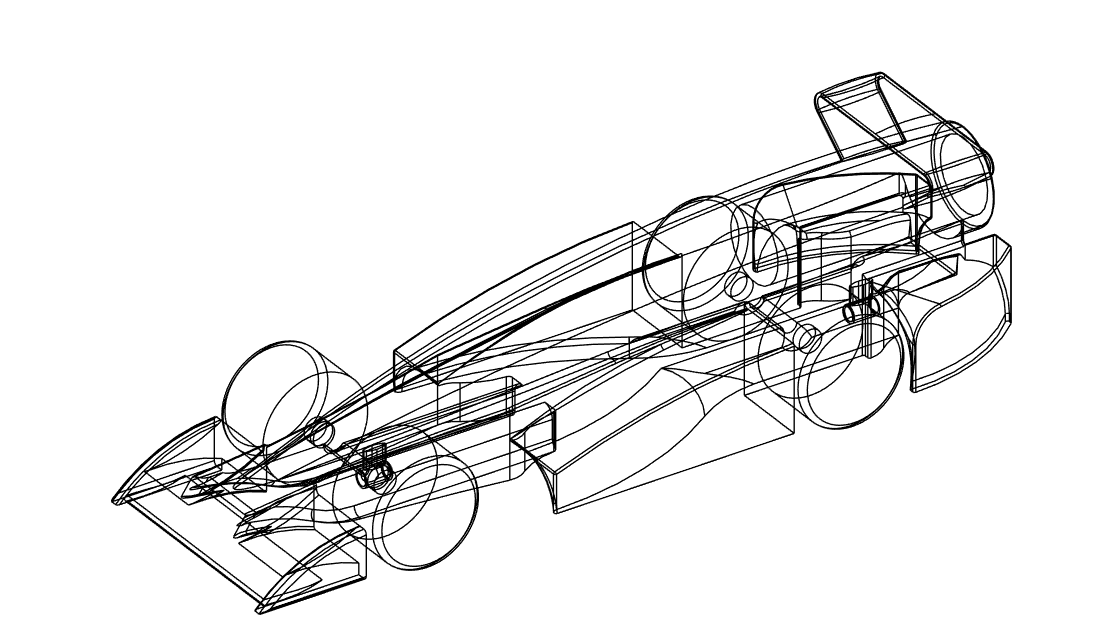
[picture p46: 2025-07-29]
media/misc. [Tests, screenshots, etc.]/Screenshot 2024-05-27 170537.png

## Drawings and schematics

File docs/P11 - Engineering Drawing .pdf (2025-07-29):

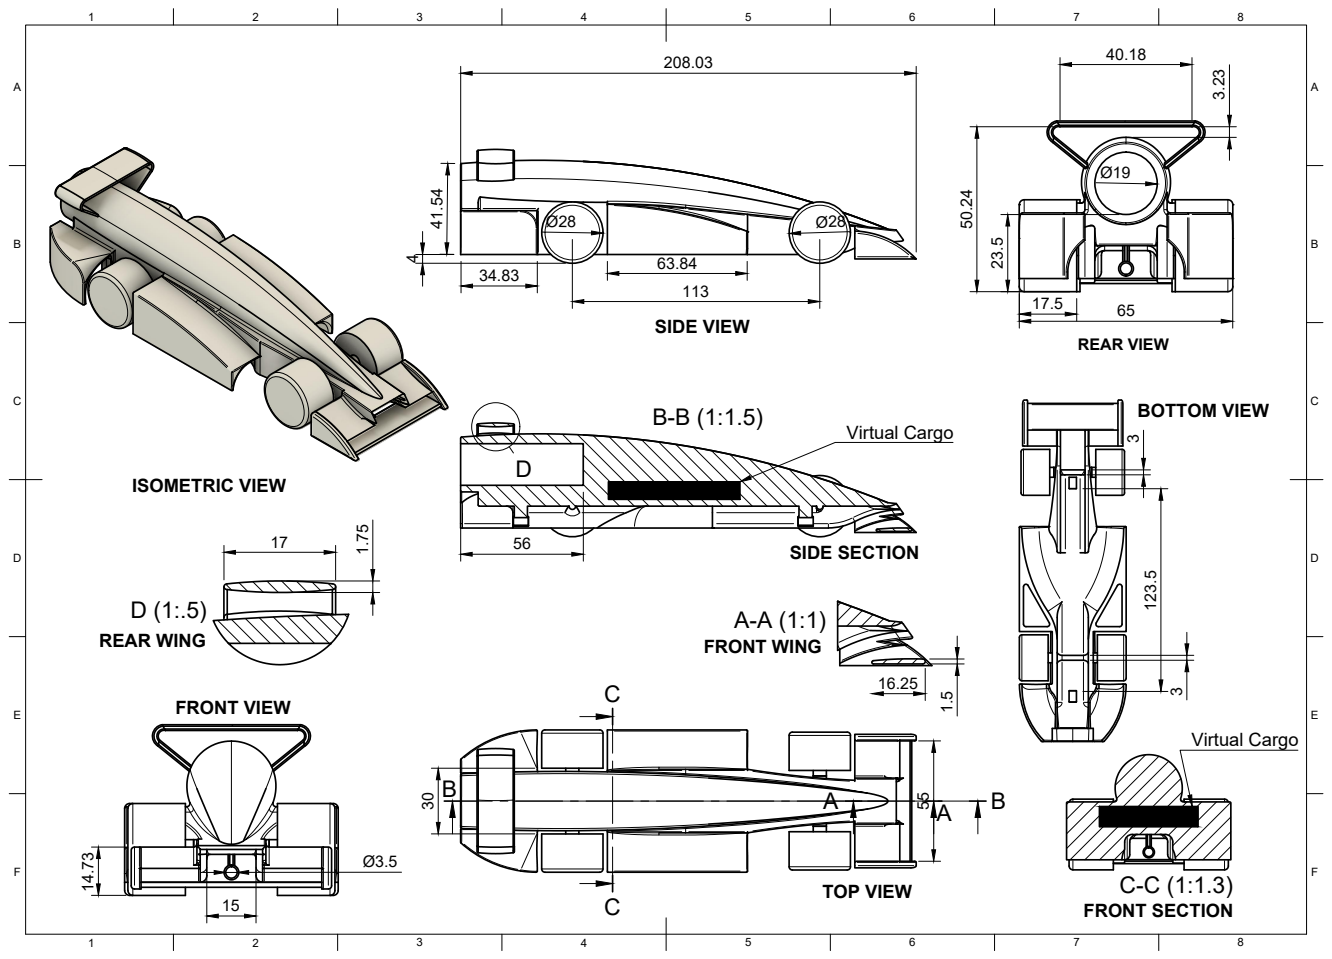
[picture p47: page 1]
REAR VIEW; SIDE VIEW; ISOMETRIC VIEW; Virtual Cargo; FRONT VIEW; TOP VIEW; REAR WING; FRONT WING; SIDE SECTION; BOTTOM VIEW; FRONT SECTION
